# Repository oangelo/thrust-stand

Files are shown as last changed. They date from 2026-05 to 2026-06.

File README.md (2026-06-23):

# thrust-stand




## 📋 Sobre

Sistema embarcado baseado em ESP32 para monitoramento de testes estáticos de motores de foguetes, com aquisição de dados de empuxo e pressão em tempo real, armazenamento em cartão SD e comunicação via Serial/Bluetooth.

## 🚀 Quick Start

1. Clone o repositório

```bash
git clone https://github.com/ViniciusCMB/thrust-stand.git
```

2. Configure o hardware conforme [esquemático](./docs/HARDWARE.md)
3. Carregue o firmware

## 📁 Estrutura do Projeto

```
├── 📂 docs/              # Documentação técnica detalhada
├── 📂 extras/            # Códigos extras utilizados
├── 📂 firmware/          # Código do microcontrolador ESP32
├── 📂 hardware/          # Esquemáticos, PCBs e lista de componentes
├── 📂 software/          # Ferramentas de análise e interface
└── 📂 tests/             # Testes unitários e de integração
```

## 🔧 Pré-requisitos

- Hardware: ESP32 DevKit V1, célula de carga + HX711, sensor de pressão (com divisor resistivo), módulo microSD (SPI), 2 botões tácteis (`GPIO32` para TARE e `GPIO33` para novo arquivo), LED com resistor de limitação
- Software: Arduino IDE 2.0+
- Bibliotecas: ver `docs/FIRMWARE.md`

## 📖 Documentação

- [Esquemático e Montagem](./docs/HARDWARE.md)
- [Firmware e Arquitetura](./docs/FIRMWARE.md)
- [Protocolos e API](./docs/API.md)
- [Troubleshooting](./docs/TROUBLESHOOTING.md)

## 🎯 Funcionalidades

- ✅ Aquisição de dados de empuxo e pressão em tempo real
- ✅ Armazenamento em cartão SD com arquivos sequenciais
- ✅ Controle local por botões (TARE e novo arquivo)
- ✅ LED de status de gravação no SD
- ✅ Comunicação (Serial, Bluetooth)
- ✅ Calibração persistente da célula de carga

## 📊 Dados de Teste

Os dados de testes estáticos de motores específicos são armazenados no repositório dedicado:
[motor](https://github.com/Serra-Rocketry/motor)

Este repositório (thrust-stand) contém apenas o sistema de aquisição. Os dados coletados durante os testes devem ser commitados no repositório `motor`.

## 🤝 Contribuindo

Este projeto segue as [Boas Práticas da Serra Rocketry](https://github.com/Serra-Rocketry/best-practices). Para contribuir:

1. Fork o projeto
2. Crie uma branch para sua feature (`git checkout -b feature/AmazingFeature`)
3. Commit suas mudanças (`git commit -m 'Add some AmazingFeature'`)
4. Push para a branch (`git push origin feature/AmazingFeature`)
5. Abra um Pull Request

## ✨ Autores

- Equipe Serra Rocketry - Desenvolvimento e documentação
- Contribuidores - [Lista de contribuidores]()

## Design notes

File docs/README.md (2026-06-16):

# 📚 Documentação Técnica - Sistema de Teste Estático

Esta documentação reúne o necessário para montagem, calibração, operação e troubleshooting do sistema baseado em ESP32.

## 🗂️ Estrutura da Documentação

### 1. Guia de Instalação

- Requisitos de hardware e software
- Configuração do ambiente
- Primeira execução

### 2. [Hardware](./HARDWARE.md)

- Lista de componentes (BOM)
- Mapeamento de pinos e conexões
- Função dos botões e do LED

### 3. [Firmware](./FIRMWARE.md)

- Arquitetura e fluxo de aquisição
- Calibração da célula de carga
- Sistema de arquivos e armazenamento

### 4. [API e Protocolos](./API.md)

- Comandos seriais
- Controles físicos
- Exemplos de interação

### 5. [Troubleshooting](./TROUBLESHOOTING.md)

- Problemas comuns e diagnóstico rápido
- Procedimentos de correção

### 6. [Evolução da Caixa](./EVOLUÇÃO_CAIXA.md)

- Histórico das 3 versões da estrutura física
- Comparativo de materiais e design

### 7. [V3 Detalhes](./V3_DETALHES.md)

- Especificações da bancada v3
- Célula de carga, guia linear, resolução

## 📊 Diagramas Técnicos

Arquitetura do sistema:

```
[Sensores] -> [ESP32] -> [Armazenamento] -> [Comunicação]
    |            |             |               |
 Célula/HX711  Process.      microSD        Serial/BT
 Pressão       Dados         Arquivo CSV    Monitoramento
```

Fluxo de dados:

```mermaid
graph TD;
    A[Sensores] --> B[Aquisição];
    B --> C[Processamento];
    C --> D[Armazenamento SD];
    C --> E[Transmissão];
    D --> F[Arquivo CSV];
    E --> G[Serial];
    E --> H[Bluetooth];
```

## 🛠️ Recursos Técnicos

### Especificações do Sistema

- Microcontrolador: ESP32
- Sensores: célula de carga (HX711) e sensor de pressão analógico
- Armazenamento: cartão SD (SPI), com fallback para LittleFS
- Comunicação: Serial USB e Bluetooth
- Controles físicos:
  - Botão `GPIO32`: TARE
  - Botão `GPIO33`: iniciar novo arquivo
  - LED `GPIO4`: aceso durante gravação no SD

### Formatos de Dados

- Logs: CSV (`Tempo,Empuxo,Pressao`)
- Configuração: `Preferences` (fator de calibração)
- Comunicação: comandos por texto

## 🤝 Contribuindo para a Documentação

1. Reporte inconsistências encontradas
2. Proponha melhorias de texto e organização
3. Abra PR com correções objetivas

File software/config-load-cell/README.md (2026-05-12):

# Explicação do Sistema

Este sistema é composto pelos seguintes componentes principais:

1. **`firmware/firmware.ino`**: roda no ESP32 e transmite leituras (RAW e em unidades) via Serial.
2. **`software/config-load-cell/fator_de_calibracao/fator_de_calibracao_main.py`**: ferramenta GUI para calcular/enviar o fator de calibração.
3. **`software/config-load-cell/fator_de_calibracao/fator_de_calibracao_cli.py`**: utilitários/CLI de calibração (opcional).

- **Firmware**: coleta dados da célula de carga (HX711) e envia via Serial/Bluetooth.
- **GUI**: lê as amostras RAW do ESP32, calcula o fator e envia via comando `SET LOAD FACTOR`.

## Passo a Passo para Configurar uma Célula do Zero

1. **Montagem do Hardware**:

   - Conecte a célula de carga ao amplificador HX711.
   - Conecte o amplificador HX711 ao ESP32.

2. **Configuração do ESP32**:

    - Carregue o código `firmware/firmware.ino` no ESP32 usando a IDE Arduino.
   - Verifique se o ESP32 está enviando dados da célula de carga via comunicação serial.

3. **Calibração da Célula de Carga**:

    - Coloque um peso conhecido na célula.
    - Execute a GUI: `python software/config-load-cell/fator_de_calibracao/fator_de_calibracao_main.py`
    - Selecione a porta serial, clique em "Conectar" e depois em "Calcular".
    - Confirme/ajuste o valor e clique em "Enviar" para persistir no ESP32.

4. **Verificação Final**:
    - Reinicie o ESP32 e valide a leitura em `kgf` via Serial (o firmware faz log contínuo).

Obs.: os arquivos `Config.ino`, `Verify.ino`, `DadosSerial.py`, `Calibrar.py` são legados e não fazem parte do fluxo atual.

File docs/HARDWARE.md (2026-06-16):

# 🔌 Hardware - Sistema de Teste Estático

## 📋 Visão Geral do Sistema

Sistema embarcado baseado em ESP32 para aquisição de empuxo e pressão em testes estáticos de motores de foguetes, com gravação local de dados no cartão SD e telemetria via Serial/Bluetooth.

Controles físicos do esquemático atual:

- `GPIO32`: botão para TARE (zerar a célula de carga)
- `GPIO33`: botão para iniciar um novo arquivo de log no SD
- `GPIO4`: LED de indicador de funcionamento (aceso durante gravação no SD)

## 🧩 Lista de Componentes (BOM)

| Componente | Quantidade | Especificações |
| --- | --- | --- |
| ESP32 DevKit V1 | 1 | 30/38 pinos, WiFi/BT |
| Célula de carga | 1 | Compatível com HX711 |
| Módulo HX711 | 1 | ADC 24 bits para célula de carga |
| Sensor de pressão | 1 | 0-10 MPa, saída analógica 0.5-4.5V |
| Módulo microSD | 1 | Interface SPI |
| LED | 1 | 5mm, vermelho |
| Botão tátil (TARE) | 1 | 6x6mm |
| Botão tátil (novo arquivo)| 1 | 6x6mm |
| Resistores do divisor | 2 | 2.2kΩ e 3.3kΩ |
| Resistor do LED | 1 | 220Ω (valor típico) |
| Fonte de alimentação | 1 | 5V 2A (mínimo recomendado) |

## 🔄 Mapeamento de Conexões

| ESP32 | Função no sistema |
| ----- | --- |
| `GPIO26` | HX711 `DT` |
| `GPIO27` | HX711 `SCK` |
| `GPIO35` | Entrada do sensor de pressão (via divisor resistivo) |
| `GPIO5`  | microSD `CS` |
| `GPIO23` | microSD `MOSI` |
| `GPIO19` | microSD `MISO` |
| `GPIO18` | microSD `SCK` |
| `GPIO4`  | LED de gravação |
| `GPIO32` | Botão TARE |
| `GPIO33` | Botão novo arquivo |
| `VIN` | Alimentação 5V dos módulos |
| `GND` | Terra comum |

Observações de ligação:

- Botões: um terminal no GPIO correspondente e o outro no `GND`.
- LED: ligado ao `GPIO4` com resistor em série.
- Sensor de pressão: saída analógica passa por divisor resistivo antes de chegar ao `GPIO35`.

## 🛠️ Procedimento de Montagem

1. Preparação dos componentes

- Verifique todos os itens da BOM
- Teste ESP32 e cartão SD separadamente antes da montagem final

2. Sequência recomendada

- Conecte alimentação (`VIN` e `GND`)
- Conecte HX711 e célula de carga
- Conecte módulo microSD (SPI)
- Conecte sensor de pressão com divisor resistivo
- Conecte LED de status
- Conecte os dois botões (`GPIO32` e `GPIO33`)

3. Divisor resistivo para o sensor de pressão

```
Vsensor (0.5-4.5V) --- R1 (2.2kΩ) --- GPIO35
                         |
                        R2 (3.3kΩ)
                         |
                        GND
```

Cálculo do divisor:

```
Vout = Vsensor * (R2 / (R1 + R2))

# Exemplo
Vout_max = 4.5V * (3300 / (2200 + 3300)) = 2.7V
```

## 📷 Foto de Referência

Montagem completa:

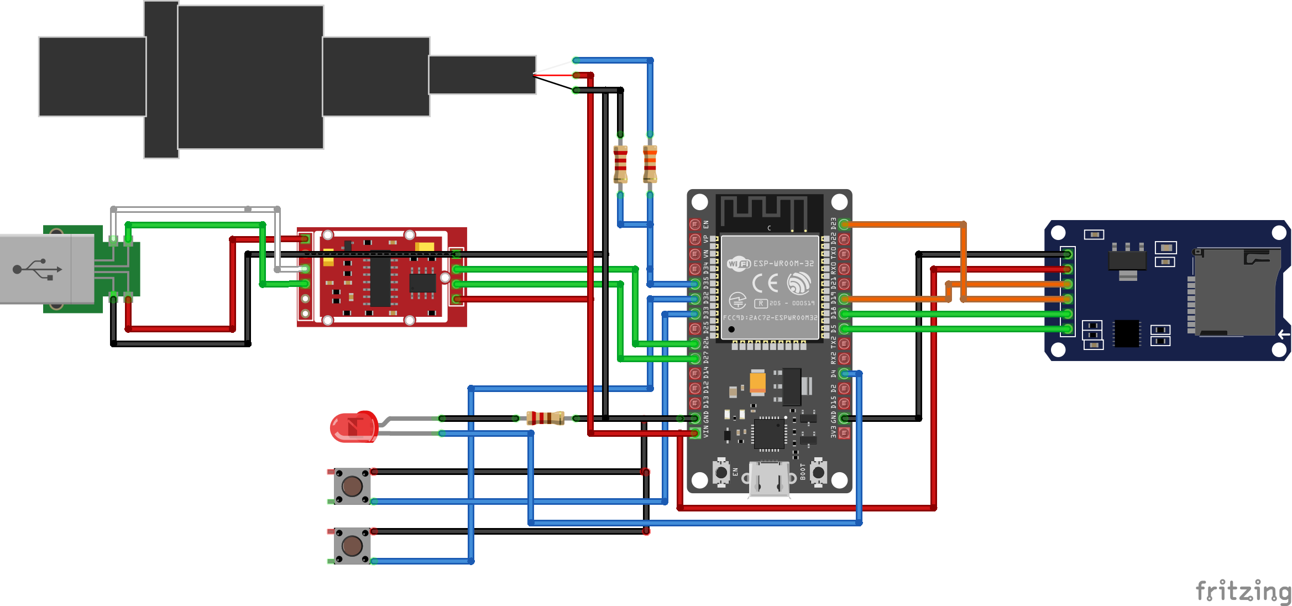
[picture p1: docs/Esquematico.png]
Esquemático


## ⚠️ Considerações de Projeto

- [x] Divisor resistivo no sensor de pressão
- [x] Terra comum entre todos os módulos
- [x] Botões dedicados para TARE e novo arquivo
- [x] LED dedicado para indicação de gravação no SD
- [ ] Isolamento contra vibrações
- [ ] Proteção contra poeira e umidade

## 🧪 Testes de Hardware

### Testes pré-montagem

- Continuidade dos cabos
- Tensão de alimentação estável
- Comunicação SPI com microSD
- Leitura de sensores individuais

### Testes pós-montagem

- Botão `GPIO32` realiza TARE
- Botão `GPIO33` inicia novo arquivo
- LED acende durante gravação no SD
- Leituras de empuxo e pressão estáveis

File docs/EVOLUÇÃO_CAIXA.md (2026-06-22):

# 📦 Evolução da Caixa de Teste Estático

## Visão Geral

Acompanha a evolução da estrutura física do sistema de teste estático ao longo de 3 versões, desde protótipo em alumínio até estrutura industrial em aço com guias lineares.

---

## V1 — Perfil V-slot 20×20mm (Alumínio)

### Estrutura

- Perfil de alumínio extrudado V-slot 20×20mm
- Formato: caixão retangular aberto
- Trilho central longitudinal
- Disco branco (prato de balança / plataforma de apoio)
- PCB verde conectada internamente
- Versão com rolamentos: dois rolamentos/flanges na travessa superior, placa de fixação metálica, eixo passante/suporte de motor

### Sensores

- 1 célula de carga fixada na base

### Fixação

- Parafusos na base (difícil de fixar no chão)

### Problemas

- Custo alto do perfil V-slot
- Robustez insuficiente
- Dificuldade de fixação no chão

### Fotos

<table>
  <tr>
    <td>V1 frontal superior</td>
    <td>V1 lateral superior</td>
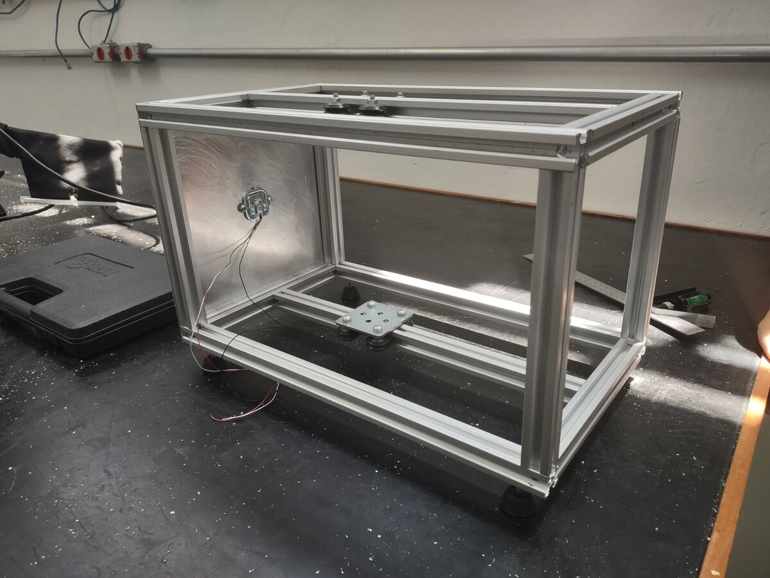
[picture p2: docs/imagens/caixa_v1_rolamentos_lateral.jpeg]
V1 com rolamentos
    <td></td>
  </tr>
</table>

### Vídeo

Teste estático V1 — alumínio

[Versão com áudio (MP4)](./videos/caixa_v1_teste_estatico.mp4)

---

## V2 — Metalon 20×20mm (Aço)

### Estrutura

- Tubo quadrado de aço (metalon) 20×20mm
- Geometria trapezoidal/triangulada (suporte para carga assimétrica)
- Pintada de preto
- Estrutura soldada (diferente da v1 modular com parafusos)

### Sensores

- 2 células de carga em encapsulamento preto
- Configuração Wheatstone (medição de empuxo + momento)

### Fixação

- Parafusos na base

### Problemas

- Soldagem difícil — estrutura ficou torta/desalinhada
- Abandonada devido à dificuldade de fabricação

### Fotos

<table>
  <tr>
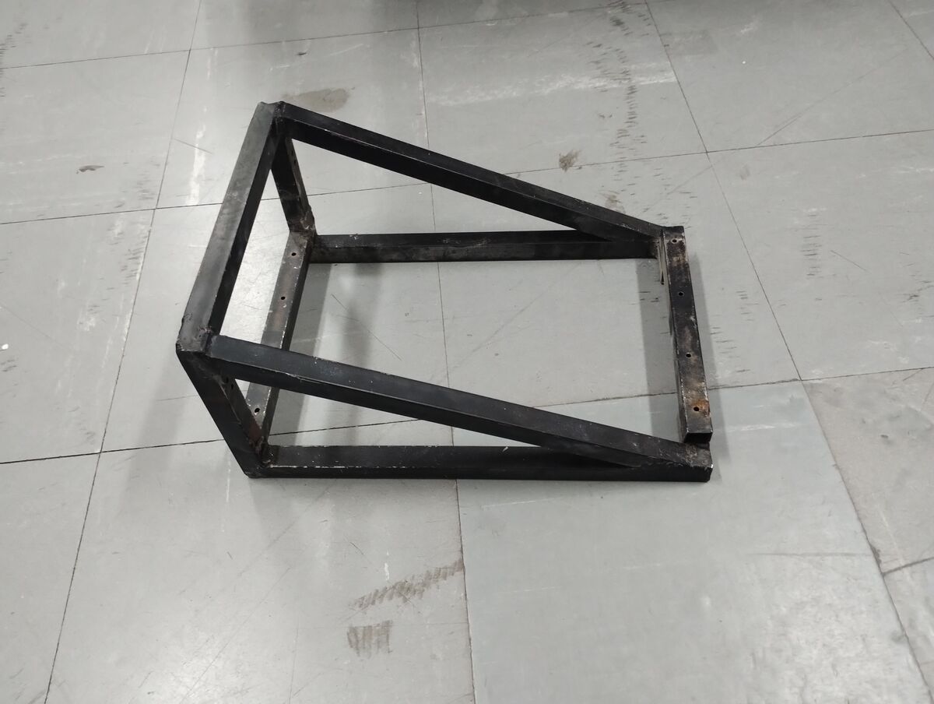
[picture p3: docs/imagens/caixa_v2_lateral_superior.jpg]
V2 lateral superior
    <td></td>
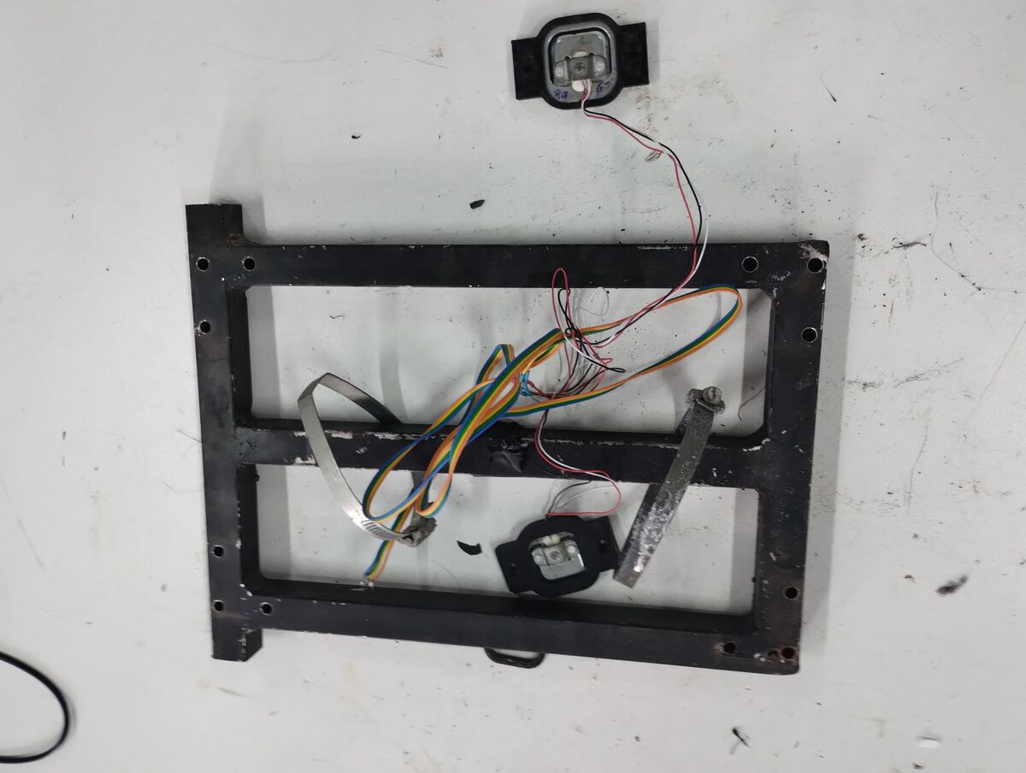
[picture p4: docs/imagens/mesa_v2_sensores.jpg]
V2 sensores
    <td></td>
  </tr>
</table>

### Vídeo

Teste estático V2 — metalon

[Versão com áudio (MP4)](./videos/caixa_v2_teste_estatico.mp4)

---

## V3 — Cantoneira 1″ × 1/4″ (Aço)

> Para especificações completas da V3, ver [V3_DETALHES.md](./V3_DETALHES.md).

### Estrutura

- Cantoneira de aço 1 polegada × 1/4 de polegada
- Mesa deslizante com trilhos lineares:
  - Dois eixos lineares cromados
  - Carrinhos lineares (rolamentos lineares)
  - Estrutura central deslizante
- Suporte de motor com fixação por flange
- Pintada de preto

### Sensores

- 1 célula de carga fixada na base

### Fixação

- Parafusos na base (melhorado em relação à v1)

### Render CAD

Mostra a base + estrutura deslizante completa. Design influenciado pelas iterações anteriores.

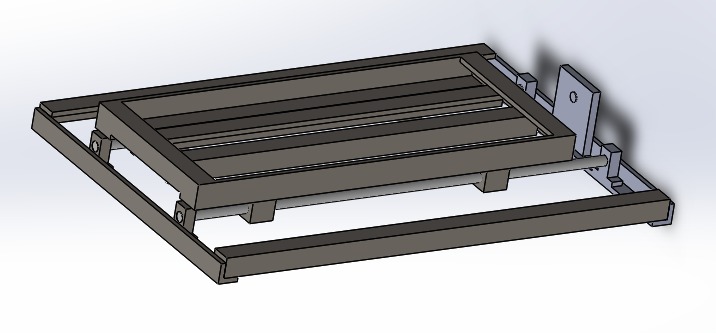
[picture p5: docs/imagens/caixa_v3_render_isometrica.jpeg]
V3 render isométrico


### Fotos

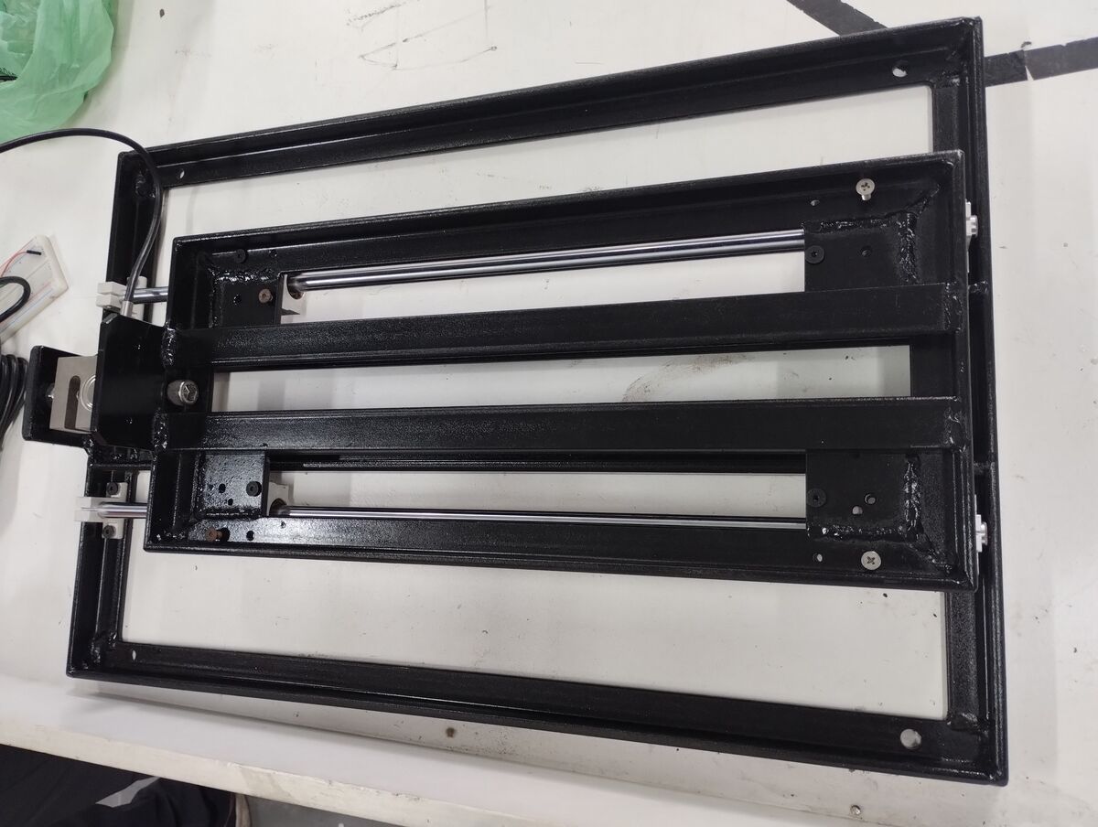
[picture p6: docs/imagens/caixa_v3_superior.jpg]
V3 superior


---

## Comparativo

| Aspecto | V1 | V2 | V3 |
| --- | --- | --- | --- |
| Material | Alumínio V-slot 20×20mm | Aço metalon 20×20mm | Aço cantoneira 1″ × 1/4″ |
| Geometria | Retangular | Trapezoidal | Retangular + mesa deslizante |
| Montagem | Modular (parafusos T-nut) | Soldada | Soldada + trilhos lineares |
| Células de carga | 1 | 2 (Wheatstone) | 1 |
| Fixação no chão  | Difícil | Melhor | Melhorada |
| Robustez | Baixa | Média | Alta |
| Custo relativo | Alto (perfil importado) | Baixo | Médio |
| Status | Abandonada | Abandonada (solda torta) | **Atual** |

---

## Conclusões

- **V1**: prototipagem rápida, explorou conceitos de guia linear e montagem modular, mas cara e frágil
- **V2**: tentativa de industrialização com geometria trapezoidal para cargas assimétricas, mas soldagem inadequada resultou em desalinhamento
- **V3**: evolução natural — combina robustez da cantoneira de aço com precisão de trilhos lineares e carrinhos, voltando à configuração de célula de carga única

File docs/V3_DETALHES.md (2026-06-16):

# 🔧 V3 — Detalhes Técnicos da Bancada

## Visão Geral

Especificações completas da versão 3 da bancada de teste estático da Serra Rocketry. Esta versão utiliza cantoneira de aço com sistema de guia linear para medição precisa de empuxo em motores experimentais de médio porte.

---

## Especificações Estruturais

| Componente | Especificação |
|---|---|
| Material da estrutura | Cantoneira de aço 1″ × 1/4″ |
| Pintura | Preto |
| Geometria | Retangular + mesa deslizante |

### Modelo CAD

[Baixar modelo STEP](../hardware/teste_estatico/step/caixa_v3.step)

---

## Sistema de Guia Linear

| Componente | Especificação |
|---|---|
| Mancal (suporte de eixo) | SK12 |
| Pillow Block (rolamento linear) | SC12UU |
| Eixo linear | ⌀12mm, comprimento 600mm |
| Tipo | Auto-alinhante (self-aligning) |
| Material do mancal | Alumínio fundido |
| Quantidade de eixos | 2 (paralelos, sem torção) |
| Fixação do Pillow Block | 16× parafusos M5×12mm |

<table>
  <tr>
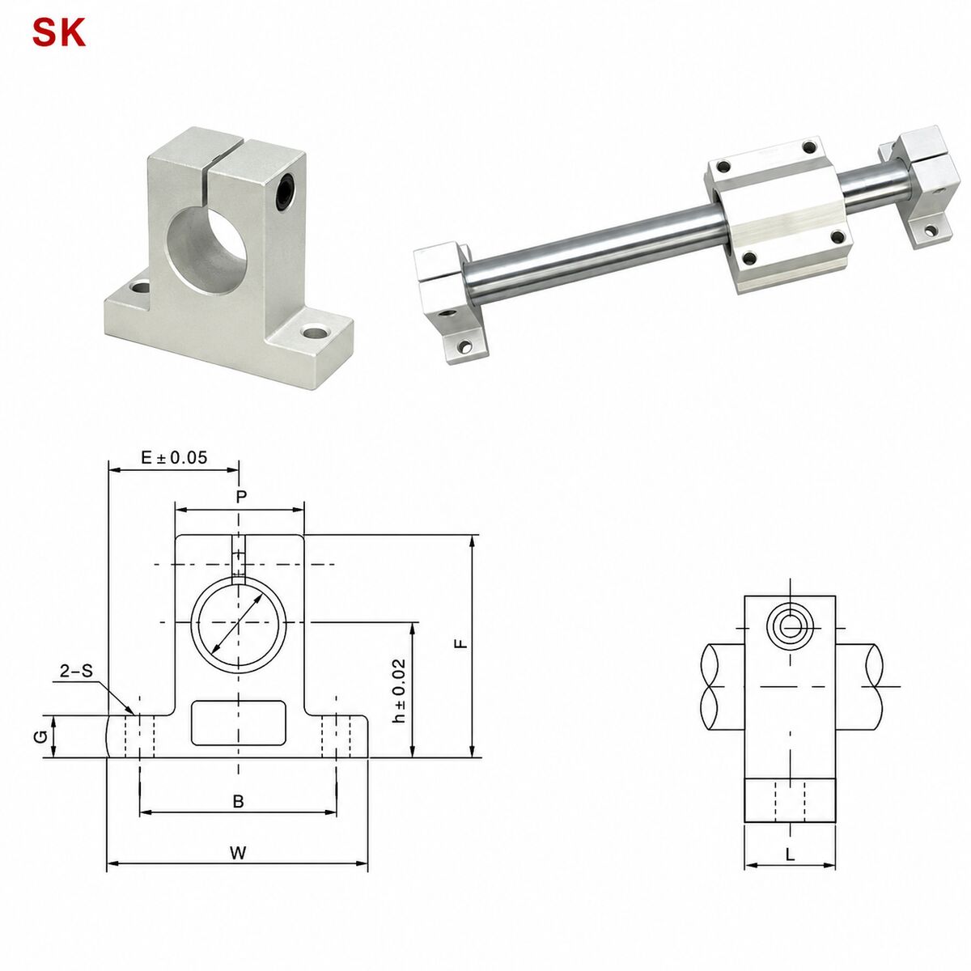
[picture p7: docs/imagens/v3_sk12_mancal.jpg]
Mancal SK12
    <td></td>
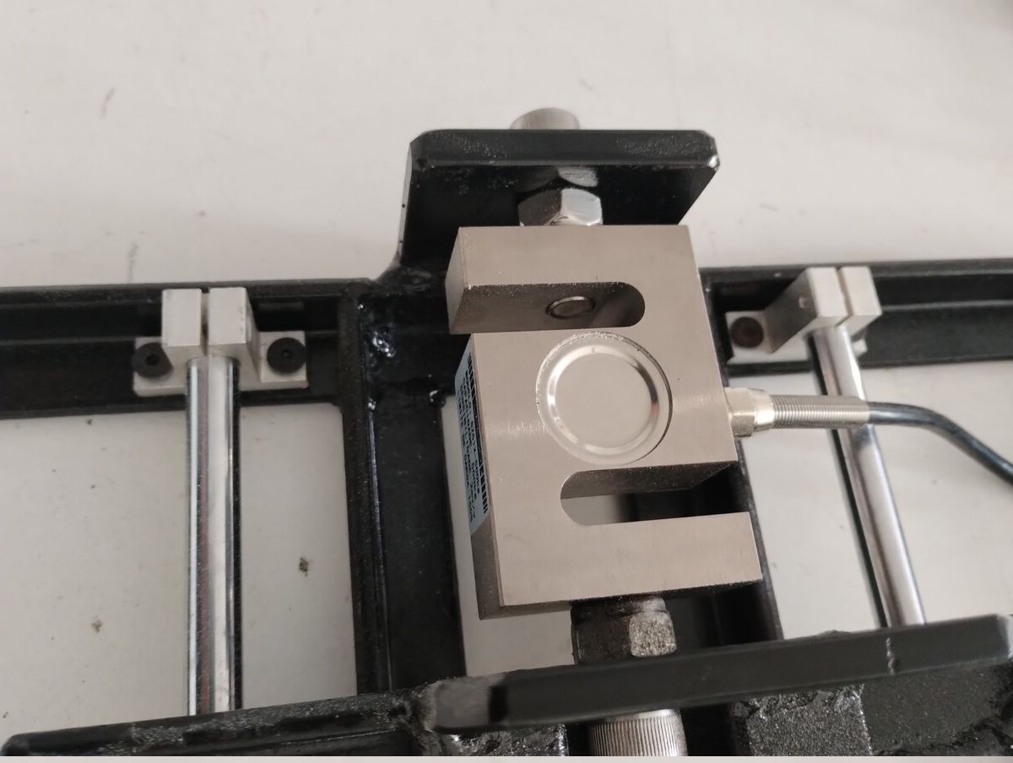
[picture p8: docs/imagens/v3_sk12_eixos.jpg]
Mancal SK12 com eixos lineares
    <td></td>
  </tr>
</table>

<table>
  <tr>
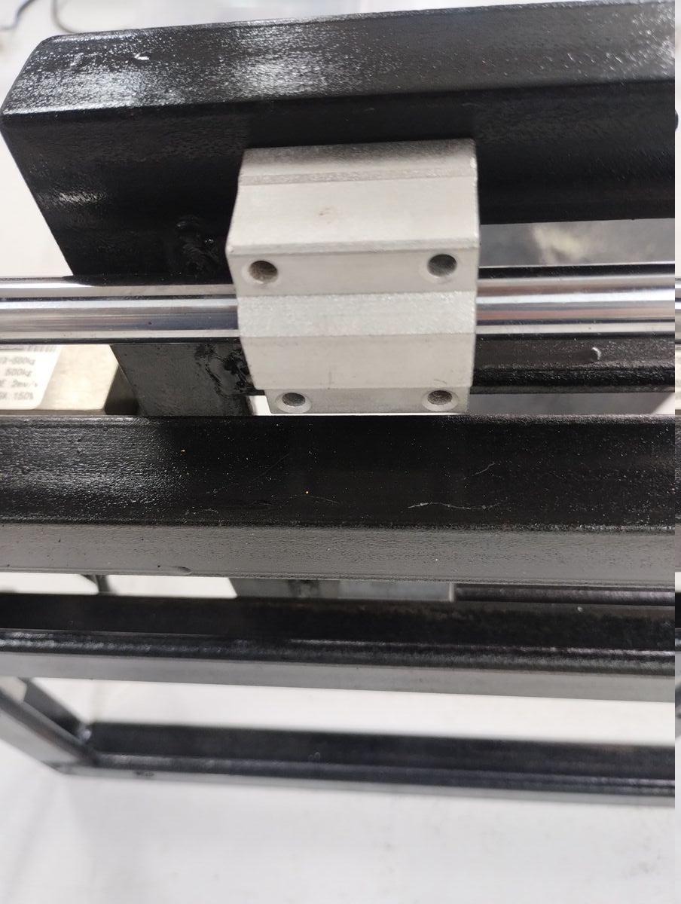
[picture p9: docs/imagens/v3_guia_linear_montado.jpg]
Guia linear montada
    <td></td>
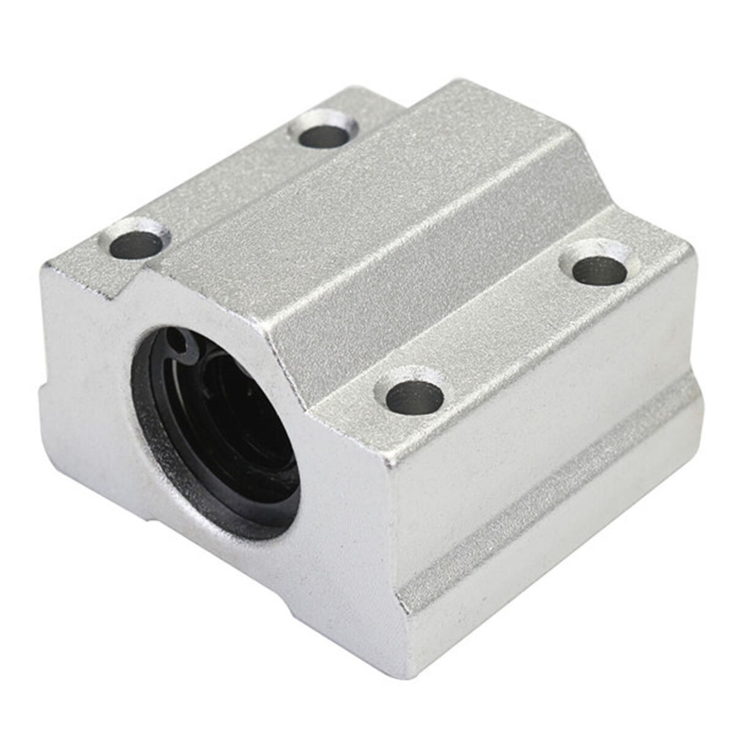
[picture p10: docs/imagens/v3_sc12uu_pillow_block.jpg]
Pillow Block SC12UU
    <td></td>
  </tr>
</table>

O sistema de guia linear permite que o carro da bancada mova-se axialmente, transmitindo o empuxo do motor para a célula de carga sem cargas laterais parasitas. Os dois eixos paralelos garantem ausência de torção.

---

## Célula de carga

### Modelo

**SZ51X-500kg** — Fabricante: PESO

- Tipo: Viga em S (shear beam)
- Material: Aço inox
- Configuração: Cisalhamento entre dois suportes metálicos

### Especificações (Certificado de Calibração)

| Parâmetro | Valor |
|---|---|
| Capacidade | 500 kgf (~4,9 kN) |
| Sensibilidade (full scale output) | 2,0 mV/V |
| Erro combinado | 0,02% F.S. |
| Não-linearidade | 0,02% F.S. |
| Repetibilidade | 0,01% F.S. |
| Histerese | 0,02% F.S. |
| Creep (30 min) | 0,02% F.S. |
| Sobrecarga segura | ±1,0% F.S. |
| Sobrecarga última | 150% F.S. |
| Impedância de entrada | 200 Ω |
| Impedância de saída | 350±5 Ω |
| Tensão de excitação | 5V (recomendado) / 12V (máx) |
| Temperatura compensada | -10 ~ +40°C |
| Temperatura de operação | -20 ~ +80°C |
| Aprovação QC | Pass 08 |

### Fiação

| Cor | Função |
|-----|---|
| Vermelho | E+ (Excitação +) |
| Preto | E− (Excitação −) |
| Verde | S+ (Sinal +) |
| Branco | S− (Sinal −) |

Célula de carga SZ51X-500kg

Célula de carga tipo viga em S em aço inox, montada em configuração de cisalhamento entre dois suportes metálicos da estrutura pintada de preto.

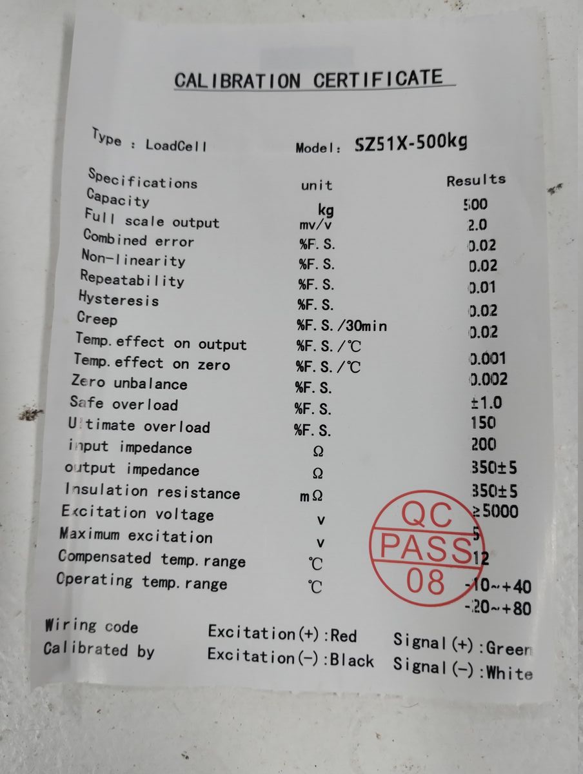
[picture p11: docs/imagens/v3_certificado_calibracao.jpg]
Certificado de calibração


Certificado do fabricante com especificações completas da SZ51X-500kg.

---

## Resolução Estimada

Com o HX711 (24 bits) ou ADS1232 na aquisição:

- **Fundo de escala:** 4,9 kN (500 kgf)
- **Resolução estimada:** ~0,5 N
- **Cobertura:** Motores experimentais de médio porte (Dédalo, Thonyan)

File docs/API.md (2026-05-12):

# 📡 API e Protocolos - Sistema de Teste Estático

## 📋 Visão Geral

Este documento descreve os protocolos de comunicação e as interfaces de controle do sistema de teste estático.

## 🔌 Protocolos Suportados

| Protocolo  | Tipo | Velocidade  | Alcance | Caso de Uso |
| --- | --- | --- | --- | --- |
| Serial USB | Fio | 115200 baud | Local | Configuração, calibração, debug |
| Bluetooth  | Wireless | 115200 baud | ~10 m | Telemetria/monitoramento |

## 💻 Comunicação Serial/Bluetooth

### Configuração padrão

```
BAUD_RATE = 115200
DATA_BITS = 8
PARITY = NONE
STOP_BITS = 1
FLOW_CONTROL = NONE
```

### Estrutura de comandos

```
COMANDO [PARAMETRO]
```

## 🎮 Comandos Disponíveis

### 1. Modo de configuração (calibração)

```
COMANDO: INIT CONFIG
RESPOSTA: Aguardando fator de carga...
USO: entra no modo de calibração da célula de carga

COMANDO: SET LOAD FACTOR <valor>
EXEMPLO: SET LOAD FACTOR 277306.0
RESPOSTA: Fator de carga atualizado
USO: salva o fator de calibração na memória persistente
```

### 2. Controle da célula de carga

```
COMANDO: TARE
RESPOSTA: Célula Zerada!
USO: zera a leitura atual da célula de carga
```

## 🕹️ Controles Físicos

| Entrada física | Pino ESP32 | Função |
| --- | --- | --- |
| Botão 1 | `GPIO32` | TARE da célula de carga |
| Botão 2 | `GPIO33` | Iniciar novo arquivo de log no SD |
| LED | `GPIO4` | Indicador de funcionamento (aceso ao gravar no SD) |

## 🎯 Exemplo de Interação

### Calibração da célula de carga

```
# Terminal -> ESP32
INIT CONFIG

# ESP32 -> Terminal
Aguardando fator de carga...
# (ESP32 envia leituras RAW continuamente)
152345
152348
152350

# Terminal -> ESP32
SET LOAD FACTOR 277306.0

# ESP32 -> Terminal
Fator de carga atualizado: 277306.00
Modo configuração finalizado
```

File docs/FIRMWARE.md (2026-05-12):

# ⚙️ Firmware - Sistema de Teste Estático

## 🏗️ Arquitetura do Sistema

### Visão Geral

O firmware implementa aquisição contínua de dados para testes estáticos, com leitura da célula de carga e do sensor de pressão, gravação em cartão SD e transmissão de logs via Serial/Bluetooth.

### Diagrama de Arquitetura

```
┌─────────────────┐    ┌──────────────────┐    ┌──────────────────┐
│   SENSORES      │    │    PROCESSAMENTO │    │     SAÍDAS       │
│                 │    │                  │    │                  │
│  Célula Carga   │───▶│   Aquisição      │───▶│  Cartão SD       │
│  Sensor Pressão │    │   Filtragem      │    │  Serial USB      │
│                 │    │   Formatação CSV │    │  Bluetooth       │
└─────────────────┘    └──────────────────┘    └──────────────────┘
         │                        │                        │
         └────────────────────────┼────────────────────────┘
                                  │
                         ┌──────────────────┐
                         │   CONTROLE       │
                         │                  │
                         │  Botão TARE      │
                         │  Novo arquivo    │
                         │  Estado do LED   │
                         └──────────────────┘
```

## 📁 Estrutura de Código

### Módulos Principais

```
firmware/
├── 📄 firmware.ino              # Arquivo principal
└── 📄 Pressure.h                # Classe sensor de pressão
```

### Dependências e Bibliotecas

- Wire
- HX711
- FS
- SD
- LittleFS
- SPI
- Pushbutton
- BluetoothSerial
- Preferences

Obs.: instale as bibliotecas acima no ambiente Arduino/PlatformIO.

## 🔧 Configuração e Calibração

### Preferências Persistentes

O sistema usa `Preferences` para salvar o fator de calibração da célula de carga.

```cpp
// Carregar configuração
loadFactor = preferences.getFloat("loadFactor", 277306.0);

// Salvar configuração
preferences.putFloat("loadFactor", loadFactor);
```

## 🔄 Fluxo de Execução

1. Inicialização (`setup()`)

```cpp
void setup() {
    Serial.begin(115200);
    SerialBT.begin("ESP32_BT");

    preferences.begin("app", false);
    loadFactor = preferences.getFloat("loadFactor", 277306.0);

    pressureSensor.begin();

    setupStorageAndFile();
    setupHX711();
}
```

2. Loop principal (`loop()`)

```cpp
void loop() {
    staticTest();  // coleta e log periódico

    // Botão 1: TARE da célula de carga
    // Botão 2: iniciar novo arquivo de log

    if (Serial.available()) {
        // comandos de calibração e controle
    }
}
```

## 📊 Aquisição de Dados

### Estrutura registrada

```csv
Tempo,Empuxo,Pressao
0,0.000000,0.000000
100,1.234567,1.902000
200,2.345678,1.955000
```

### Processo de log

- Leitura da célula de carga (`HX711`)
- Leitura do sensor de pressão (`PressureSensor`)
- Atualização de picos de leitura
- Escrita no arquivo CSV atual no SD/LittleFS
- Espelhamento da leitura em Serial/Bluetooth

## 🎮 Controle do Sistema

### Interface Serial/Bluetooth

Os comandos são recebidos pela Serial USB. A Bluetooth serial espelha mensagens de log/estado.

### Comandos disponíveis

| Comando | Descrição | Exemplo | Resposta esperada |
| --- | --- | --- | --- |
| INIT CONFIG | Entra em modo calibração | `INIT CONFIG` | Aguarda fator de carga |
| SET LOAD FACTOR | Define fator de carga | `SET LOAD FACTOR 277306.0` | Fator atualizado |
| TARE | Zera célula de carga | `TARE` | Célula zerada |

### Entradas físicas

- Botão em `GPIO32`: executa TARE da célula de carga
- Botão em `GPIO33`: inicia um novo arquivo para continuação do teste
- LED em `GPIO4`: aceso durante gravação no cartão SD

## 💾 Sistema de Arquivos

### Estratégia de armazenamento

- O firmware tenta inicializar o cartão SD
- Em falha do SD, usa LittleFS como fallback
- Arquivos são gerados em sequência (`Dados_001.txt`, `Dados_002.txt`, ...)

### Formato do arquivo de dados

```csv
Tempo,Empuxo,Pressao
0,0.000000,0.000000
100,1.234567,1.902000
```

## 📡 Comunicação

- Serial USB: configuração, calibração e debug
- Bluetooth: espelhamento de leituras/estado

## 🚀 Compilação e Upload

### Arduino IDE

1. Selecione a placa `ESP32 Dev Module`
2. Configure a porta serial correta
3. Verifique as bibliotecas instaladas
4. Compile e faça upload

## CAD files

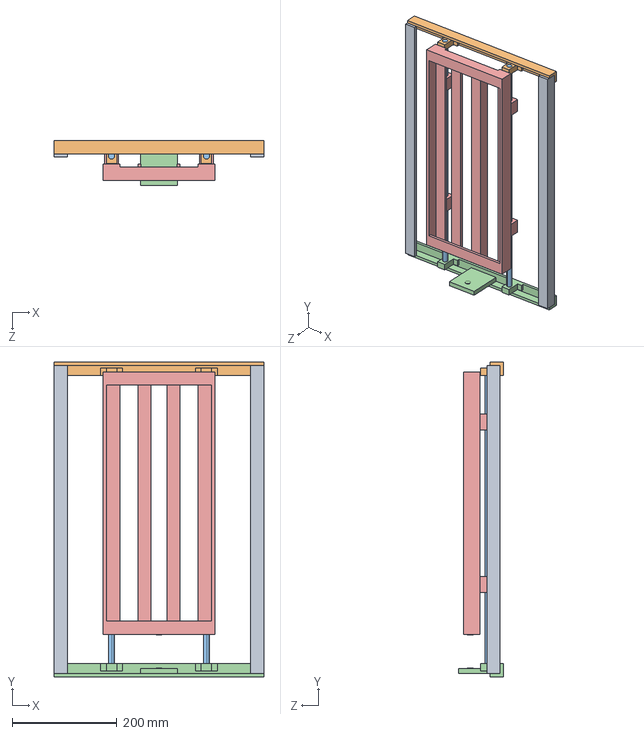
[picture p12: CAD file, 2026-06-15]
hardware/teste_estatico/step/caixa_v3.step
400.0 x 600.0 x 85.5 mm
Caixa_Teste_Estático_Basev3
Caixa_Teste_Estático_carrinhov3

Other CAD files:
hardware/teste_estatico/Fusion 360/testeserra1.f3z

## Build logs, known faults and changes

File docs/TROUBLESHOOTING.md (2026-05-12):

# 🐛 Troubleshooting - Sistema de Teste Estático

## 📋 Visão Geral

Guia rápido para diagnosticar falhas de alimentação, gravação no SD, leitura de sensores e controle por botões.

## 🔍 Diagnóstico Rápido

### LED de funcionamento (`GPIO4`)

| Estado do LED | Significado | Ação |
| --- | --- | ---- |
| Aceso | Sistema gravando no SD | Operação normal |
| Apagado durante gravação esperada | Sem escrita no arquivo atual | Verificar SD e fluxo de gravação |

### Botões físicos

| Botão | Pino | Função esperada |
| ----- | ---- | --- |
| Botão 1 | `GPIO32` | TARE da célula de carga |
| Botão 2 | `GPIO33` | Iniciar novo arquivo no SD |

## 🚨 Problemas Comuns e Soluções

### 1. 🔌 Problemas de alimentação

Sintomas:

- Sistema não liga
- Reinicializações aleatórias
- Leituras instáveis

Soluções:

```
1. Medir 5V em VIN e 3.3V no ESP32
2. Confirmar fonte com corrente suficiente (>= 2A recomendado)
3. Testar com outro cabo USB/fonte
4. Confirmar GND comum entre todos os módulos
```

### 2. 💾 Problemas com cartão SD

Sintomas:

- Falha ao iniciar armazenamento
- Arquivo não é criado
- LED não acende quando deveria gravar

Soluções:

```
1. Verificar formatação FAT32
2. Verificar conexões SPI: CS(5), MOSI(23), MISO(19), SCK(18)
3. Testar outro cartão SD
4. Verificar alimentação e GND do módulo SD
```

### 3. ⚖️ Problemas com célula de carga / HX711

Sintomas:

- Leitura travada em valor fixo
- Leitura muito ruidosa
- TARE não zera

Soluções:

```
1. Verificar DT(GPIO26) e SCK(GPIO27)
2. Verificar ligação da célula no HX711
3. Executar TARE pelo botão GPIO32 e por comando serial (TARE)
4. Repetir calibração com peso conhecido
```

### 4. 📊 Problemas com sensor de pressão

Sintomas:

- Leitura em 0 constante
- Saturação em valor máximo
- Oscilação elevada

Soluções:

```
1. Verificar alimentação do sensor
2. Verificar divisor resistivo (2.2kΩ e 3.3kΩ)
3. Medir tensão no GPIO35 (faixa esperada: 0-3.3V)
4. Conferir GND comum entre sensor e ESP32
```

### 5. 🎛️ Problemas nos botões

Sintomas:

- Botão de TARE não responde
- Botão de novo arquivo não cria novo log

Soluções:

```
1. Conferir ligação dos botões para GND
2. Conferir pinos corretos: GPIO32 (TARE), GPIO33 (novo arquivo)
3. Verificar mau contato no botão/chicote
4. Testar acionamento com monitor serial aberto
```

### 6. 📡 Problemas de comunicação Serial/Bluetooth

Sintomas:

- Sem dados no terminal serial
- Bluetooth não encontra o dispositivo

Soluções:

```
1. Confirmar baud rate 115200
2. Testar outro cabo USB
3. Confirmar porta serial correta
4. Reiniciar ESP32 e reconectar Bluetooth
```

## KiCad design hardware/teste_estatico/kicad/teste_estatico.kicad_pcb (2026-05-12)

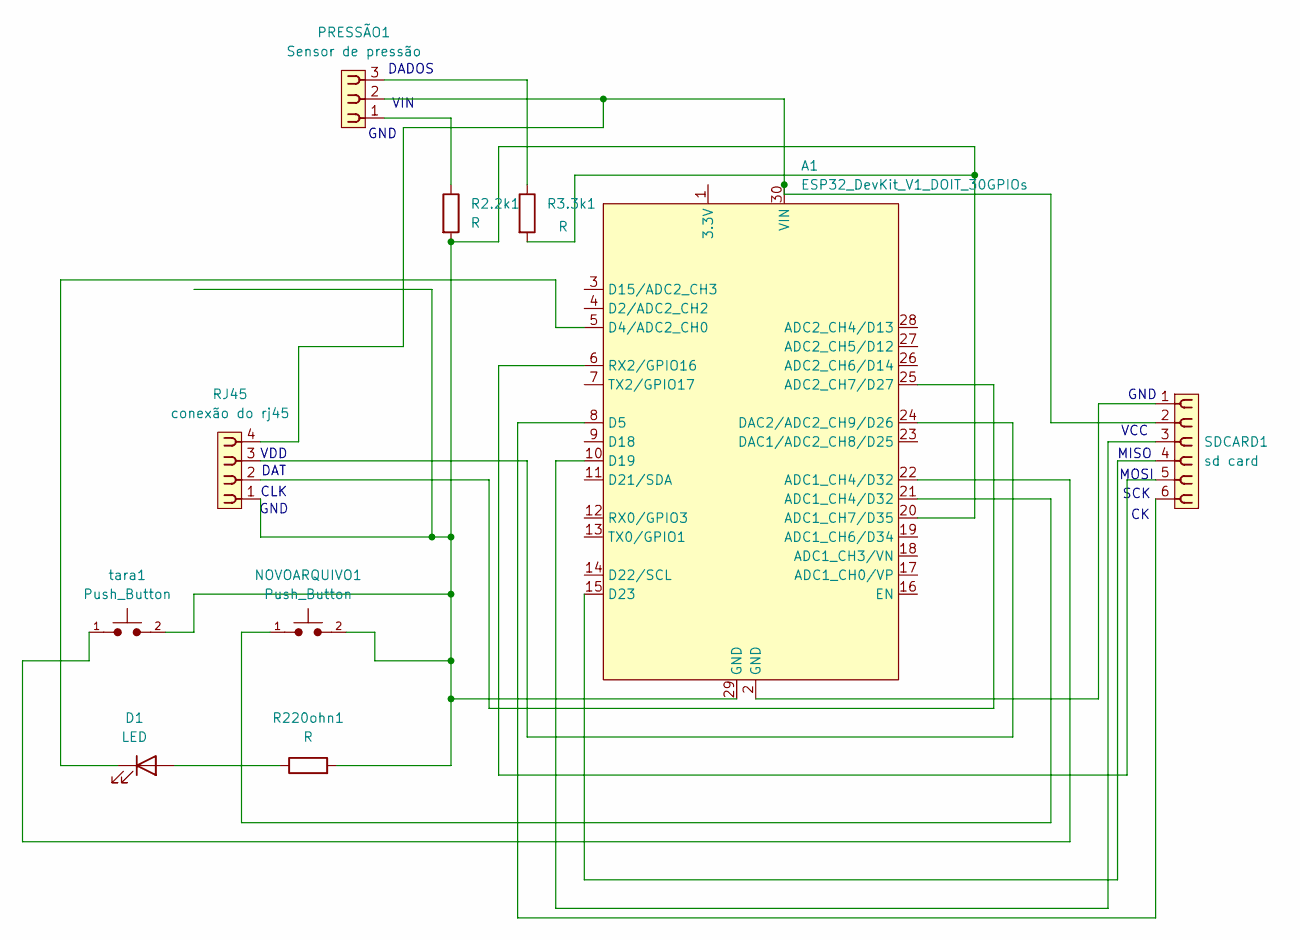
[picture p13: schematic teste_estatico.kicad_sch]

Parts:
A1: ESP32_DevKit_V1_DOIT_30GPIOs; DOIT_ESP32_DEVKIT_30Pins
D1: LED; LED_D5.0mm_FlatTop
NOVOARQUIVO1: Push_Button; SW_PUSH_6mm
PRESSÃO1: Sensor de pressão; PinSocket_1x03_P2.54mm_Vertical
R2.2k1, R3.3k1, R220ohn1: R; R_Axial_DIN0309_L9.0mm_D3.2mm_P12.70mm_Horizontal
RJ45: conexão do rj45; PinSocket_1x04_P2.54mm_Vertical
SDCARD1: sd card; PinSocket_1x06_P2.54mm_Vertical
tara1: Push_Button; SW_PUSH_6mm

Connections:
unnamed: A1.21 (ADC1_CH4/D32), NOVOARQUIVO1.1
unnamed: A1.22 (ADC1_CH4/D32), tara1.1
unnamed: A1.20 (ADC1_CH7/D35), A1.29 (GND), NOVOARQUIVO1.2, R2.2k1.2, R3.3k1.2, R220ohn1.2, RJ45.1, tara1.2
unnamed: A1.25 (ADC2_CH7/D27), RJ45.2
unnamed: A1.5 (D4/ADC2_CH0), D1.1 (K)
unnamed: A1.8 (D5), SDCARD1.6
unnamed: A1.10 (D19), SDCARD1.3
unnamed: A1.15 (D23), SDCARD1.4
unnamed: A1.24 (DAC2/ADC2_CH9/D26), RJ45.3
unnamed: A1.2 (GND), SDCARD1.1
unnamed: A1.6 (RX2/GPIO16), SDCARD1.5
unnamed: A1.30 (VIN), PRESSÃO1.2, RJ45.4, SDCARD1.2
unnamed: D1.2 (A), R220ohn1.1
unnamed: PRESSÃO1.1, R2.2k1.1
unnamed: PRESSÃO1.3, R3.3k1.1

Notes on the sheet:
DADOS
DAT
SCK
GND
CLK
VIN
VCC
MOSI
VDD
MISO

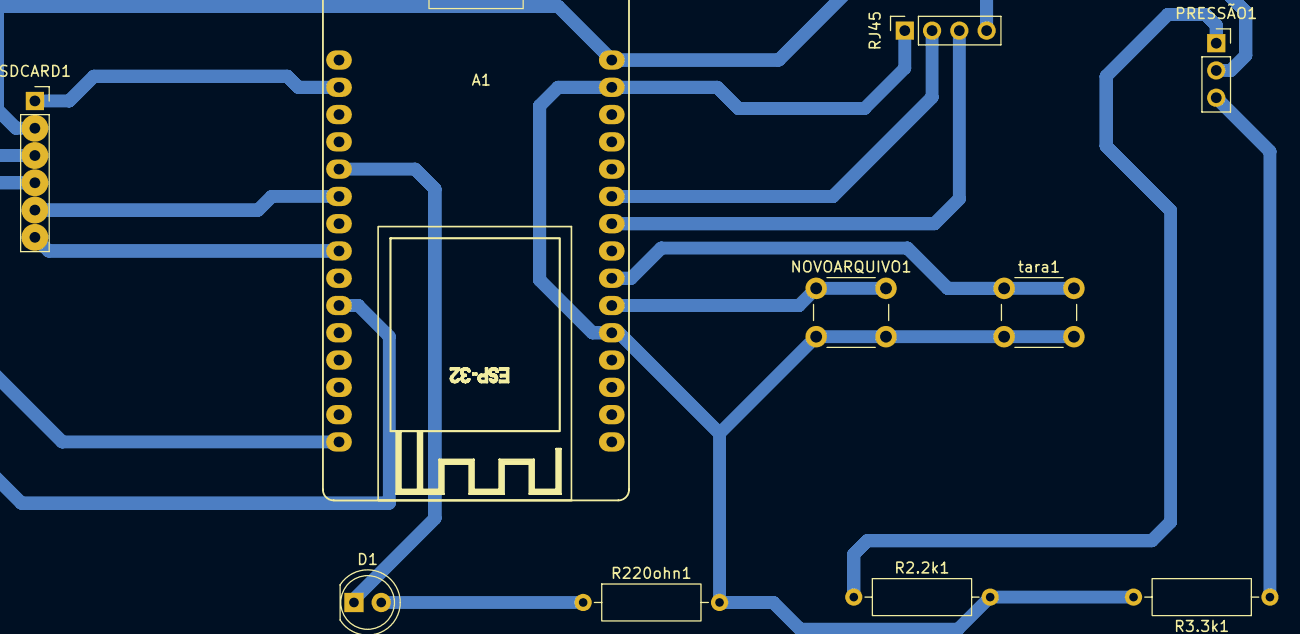
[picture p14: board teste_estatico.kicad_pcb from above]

Board: 2 copper layers, 10 parts (0 on the bottom side), 15 nets.

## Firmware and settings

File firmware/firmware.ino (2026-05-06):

// INCLUSÃO DE BIBLIOTECAS
#include <Wire.h>
#include <HX711.h>
#include <FS.h>
#include <SD.h>
#include <LittleFS.h>
#include <SPI.h>
#include <Pushbutton.h>
#include <BluetoothSerial.h>
#include <Preferences.h>

#include "Pressure.h"

// Definições de pinos e constantes
#define LED_PIN 4     // Pino do LED
#define CS_PIN 5      // Pino do cartão SD
#define BUZZER_PIN 33 // Pino do buzzer
#define BTN_PIN 32    // Pino do botão
#define CELULA_DT_PIN 26  // Pino de dados da célula de carga
#define CELULA_SCK_PIN 27 // Pino de clock da célula de carga
#define PRESSURE_PIN 35   // Pino do sensor de pressão
#define INTERVALO 100     // Precisão Leitura Dados milissegundos

// Sensores analógicos no ESP32 podem variar com atenuação/referência.
// Ajuste estes parâmetros ao seu hardware real para obter leituras coerentes.

// Variáveis globais
const float VinPressure = 5.0;    // Tensão que alimenta o sensor
const float VminPressure = 0.27;  // Tensão de saída em 0 MPa
const float VmaxPressure = 4.5;   // Tensão de saída em 10 MPa
const float maxPressure = 10.0;   // Pressão máxima do sensor em MPa
const float R1 = 2200.0;          // Resistor conectado entre o sensor e o pino do ESP32
const float R2 = 3300.0;          // Resistor conectado entre o pino do ESP32 e o GND
const int RESOLUCAO_ADC = 4095;   // ESP32 tem ADC de 12 bits (2^12 - 1)
const float TENSAO_MAX_ADC = 3.3; // Tensão de referência do ADC do ESP32
float maxValues[2] = {0.0, 0.0};  // Vetor leituras de pico (peso, pressão)
unsigned long previousMillis = 0; // Controle de tempo
bool selectLoop = false;          // Modo de operação
float loadFactor = 0.0;           // Valor encontrado na calibração
String filedir = "";              // Arquivo
String leitura = "";              // Leitura dos dados

enum StorageType { STORAGE_NONE, STORAGE_SD, STORAGE_LITTLEFS };
StorageType storageType = STORAGE_NONE;

// Estado do modo de configuração (calibração)
static bool configMode = false;

// Instanciação de objetos
Pushbutton button(BTN_PIN);                                                                                                  // Botão
PressureSensor pressureSensor(PRESSURE_PIN, R1, R2, RESOLUCAO_ADC, TENSAO_MAX_ADC, VminPressure, VmaxPressure, maxPressure); // Sensor de pressão

HX711 escala;                                                                                                                // Célula de carga
BluetoothSerial SerialBT;                                                                                                    // Bluetooth
Preferences preferences;                                                                                                     // Preferências salvas

void setup()
{
  // Inicialização da comunicação serial
  Serial.begin(115200);
  SerialBT.begin("ESP32_BT");

  preferences.begin("app", false);
  loadFactor = preferences.getFloat("loadFactor", 277306.0);

  pinMode(LED_PIN, OUTPUT);
  pinMode(BUZZER_PIN, OUTPUT);
  pinMode(BTN_PIN, INPUT);

  pressureSensor.begin();

  if (setupStorageAndFile() && setupHX711())
  {
    printToSerials("Sistema configurado. Transmitindo...");
    buzzSignal("Sucesso");
  }
  else
  {
    printToSerials("Falha crítica. Reiniciando...");
    buzzSignal("Alerta");
    delay(3000);
    ESP.restart();
  }
}

void loop()
{
  if (!configMode)
  {
    staticTest();
  }

  if (button.getSingleDebouncedPress())
  {
    buzzSignal("Beep");
    printToSerials("Célula Zerada!");
    escala.tare();
  }

  if (Serial.available())
  {
    String command = Serial.readStringUntil('\n');
    command.trim(); // Remove espaços e quebras de linha

    if (command.equalsIgnoreCase("TARE"))
    {
      buzzSignal("Beep");
      printToSerials("Célula Zerada!");
      escala.tare();
      return;
    }

    if (command.startsWith("INIT CONFIG"))
    {
      escala.tare();
      configMode = true;
      Serial.println("Aguardando fator de carga...");
      return;
    }

    if (configMode && command.startsWith("SET LOAD FACTOR"))
    {
      int lastSpaceIndex = command.lastIndexOf(' ');
      if (lastSpaceIndex != -1)
      {
        String factorStr = command.substring(lastSpaceIndex + 1);
        float factor = factorStr.toFloat();
        if (!isnan(factor) && factor != 0.0)
        {
          setLoadFactor(factor);
          configMode = false;
          Serial.println("Modo configuração finalizado");
        }
        else
        {
          printToSerials("Valor inválido. Tente novamente.");
          buzzSignal("Alerta");
        }
      }
      return;
    }
  }

  // Stream de calibração: RAW contínuo enquanto aguarda o fator
  if (configMode)
  {
    Serial.println(escala.get_value(1));
    delay(100);
  }
}

// Configuração do fator de carga
void setLoadFactor(float factor)
{
  loadFactor = factor;
  escala.set_scale(loadFactor);
  preferences.putFloat("loadFactor", loadFactor);
  printToSerials("Fator de carga atualizado: " + String(loadFactor, 2));
  buzzSignal("Sucesso");
}

// Sinalização com o buzzer
void buzzSignal(String signal)
{
  int frequency = 1000;   // Frequência do tom
  if (signal == "Alerta") // Alerta de erro em alguma configuração
  {
    for (int i = 0; i < 5; i++)
    {
      tone(BUZZER_PIN, frequency, 200);
      delay(200 + 150);
    }
  }
  else if (signal == "Sucesso") // Sinal de sucesso na configuração
  {
    for (int i = 0; i < 3; i++)
    {
      tone(BUZZER_PIN, frequency, 100);
      delay(100 + 100);
    }
  }
  else if (signal == "Ativado")
  {
    tone(BUZZER_PIN, frequency, 500);
  }
  else if (signal == "Beep") // Beep de funcionamento padrão
  {
    tone(BUZZER_PIN, frequency, 50);
  }
  else
  {
    Serial.println("Sinal inválido!");
  }
}


String generateFileName()
{
  const char* prefix = (storageType == STORAGE_SD) ? "Dados" : "dados";

  for (int i = 1; i <= 999; i++)
  {
    char candidate[32];
    snprintf(candidate, sizeof(candidate), "/%s_%03d.txt", prefix, i);

    bool exists = false;
    if (storageType == STORAGE_SD) {
      exists = SD.exists(candidate);
    } else if (storageType == STORAGE_LITTLEFS) {
      exists = LittleFS.exists(candidate);
    }

    if (!exists)
      return String(candidate);
  }

  return "/overflow.txt";
}

// Configuração do Storage (SD com LittleFS fallback)
bool setupStorage()
{
  Serial.println("Inicializando SD...");
  if (SD.begin(CS_PIN) && SD.cardType() != CARD_NONE)
  {
    storageType = STORAGE_SD;
    Serial.println("SD iniciado!");
    Serial.printf("Tipo: %s\n",
      SD.cardType() == CARD_MMC ? "MMC" :
      SD.cardType() == CARD_SD ? "SDSC" :
      SD.cardType() == CARD_SDHC ? "SDHC" : "UNKNOWN");
    return true;
  }

  Serial.println("SD falhou. Tentando LittleFS...");
  yield();

  if (LittleFS.begin(true))
  {
    storageType = STORAGE_LITTLEFS;
    Serial.println("LittleFS iniciado!");
    Serial.printf("Total: %u bytes, Usado: %u bytes\n",
      (unsigned)LittleFS.totalBytes(), (unsigned)LittleFS.usedBytes());
    return true;
  }

  Serial.println("ERRO: Nenhum storage disponivel!");
  yield();
  return false;
}

// Configuração do Storage e Arquivo
bool setupStorageAndFile()
{
  if (!setupStorage())
  {
    return false;
  }

  filedir = generateFileName();
  Serial.print("Arquivo: ");
  Serial.println(filedir);

  if (!writeFile(filedir, "Tempo,Empuxo,Pressao\n"))
  {
    printToSerials("Falha ao criar arquivo");
    return false;
  }

  printToSerials("Arquivo criado: " + filedir);
  return true;
}

// Configuração da célula de carga HX711
bool setupHX711()
{
  Serial.println("Iniciando HX711...");
  escala.begin(CELULA_DT_PIN, CELULA_SCK_PIN);
  Serial.println("HX711.begin OK");

  escala.set_scale(loadFactor);
  Serial.println("set_scale OK");

  escala.tare();
  Serial.println("tare OK");

  printToSerials("HX711 conectado");
  return true;
}

// Função para registrar e imprimir os dados do momento
// Formato: Tempo (ms), Empuxo (Kg), Pressão (MPa)
void logData(unsigned long millis)
{
  float peso = escala.get_units();
  float pressao = pressureSensor.readMPa();

  if (peso > maxValues[0])
  {
    maxValues[0] = peso;
  }

  if (pressao > maxValues[1])
  {
    maxValues[1] = pressao;
  }

  leitura = String(millis) + "," + String(peso, 6) + "," + String(pressao);

  printToSerials(leitura);
  appendFile(filedir, leitura);
}

// Escrita de dados em um arquivo
bool writeFile(const String &path, const String &message)
{
  File file;

  if (storageType == STORAGE_SD) {
    file = SD.open(path, FILE_WRITE);
  } else if (storageType == STORAGE_LITTLEFS) {
    file = LittleFS.open(path, FILE_WRITE);
  } else {
    return false;
  }

  if (!file)
  {
    printToSerials("Falha ao abrir o arquivo");
    return false;
  }
  if (file.print(message))
  {
    digitalWrite(LED_PIN, HIGH);
  }
  else
  {
    printToSerials("Falha ao escrever no arquivo");
    digitalWrite(LED_PIN, LOW);
    file.close();
    return false;
  }
  file.close();
  return true;
}

// Anexação de dados em um arquivo
void appendFile(const String &path, const String &message)
{
  File file;

  if (storageType == STORAGE_SD) {
    file = SD.open(path, FILE_APPEND);
  } else if (storageType == STORAGE_LITTLEFS) {
    file = LittleFS.open(path, FILE_APPEND);
  } else {
    return;
  }

  if (!file)
  {
    printToSerials("Falha ao abrir o arquivo");
    return;
  }
  if (file.print(message + "\n"))
  {
    digitalWrite(LED_PIN, HIGH);
  }
  else
  {
    printToSerials("Falha ao escrever no arquivo");
    digitalWrite(LED_PIN, LOW);
  }
  file.close();
}

// Criação de diretório
void createDir(fs::FS &fs, const String &path)
{
  if (fs.mkdir(path))
  {
    printToSerials("Dir created");
  }
  else
  {
    printToSerials("mkdir failed");
  }
}

// Função para imprimir na Serial e SerialBT
void printToSerials(const String &message)
{
  Serial.println(message);
  SerialBT.println(message);
}

// Função de teste estático
void staticTest()
{
  unsigned long currentMillis = millis();
  if (currentMillis - previousMillis > INTERVALO)
  {
    logData(currentMillis);
    previousMillis = currentMillis;
  }
}

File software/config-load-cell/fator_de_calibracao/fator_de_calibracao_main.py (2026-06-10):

import sys
from PySide6.QtWidgets import QApplication, QMainWindow
from PySide6.QtCore import QThread, Signal
import fator_de_calibracao_cli as fact_cli
import ui_fator_de_calibracao as fact_ui
import logging


class SamplerThread(QThread):
    """Coleta amostras da serial em background, sem travar a UI."""

    progress        = Signal(int)   # 0–100
    sample_received = Signal(int)   # valor de cada amostra
    finished        = Signal(list)  # lista final de amostras
    error           = Signal(str)   # mensagem de erro

    def __init__(self, com: fact_cli.Receiver, n_samples: int = 100):
        super().__init__()
        self.com = com
        self.n_samples = n_samples
        self._running = True

    def run(self):
        samples = []
        sample_count = 0

        # Garante que o ESP está em configMode antes de coletar.
        # Manda INIT CONFIG e aguarda a confirmação, com até 10 tentativas.
        confirmed = False
        for attempt in range(10):
            self.com.serial.reset_input_buffer()
            self.com.send_command(b'INIT CONFIG\n')
            # Lê algumas linhas esperando a confirmação
            for _ in range(5):
                line = self.com.read_response()
                print(f"[handshake] {repr(line)}")
                if 'Aguardando' in line or 'CONFIG' in line.upper():
                    confirmed = True
                    break
            if confirmed:
                print(f"[handshake] configMode confirmado na tentativa {attempt + 1}")
                break

        if not confirmed:
            self.error.emit('ESP não confirmou modo de calibração. Verifique a conexão.')
            return

        # Limpa qualquer lixo que chegou durante o handshake
        self.com.serial.reset_input_buffer()

        try:
            while self._running and self.com.check_connection() and sample_count < self.n_samples:
                raw = self.com.read_response()
                print(f"raw={repr(raw)}")
                value = fact_cli.try_parse_int(raw)
                if value is None:
                    continue
                samples.append(value)
                sample_count += 1
                self.sample_received.emit(value)
                self.progress.emit(int(sample_count / self.n_samples * 100))
        except Exception as e:
            self.error.emit(str(e))
            return

        self.finished.emit(samples)

    def stop(self):
        self._running = False


class Calibrator:

    def __init__(self):
        self.app = QApplication(sys.argv)
        self.window = QMainWindow()
        self.ui = fact_ui.Ui_MainWindow()
        self.logger = logging.getLogger('Calibrator')
        self.ui.setupUi(self.window)
        self.stopper = extend_ui(self.ui)
        self.window.show()
        self.app.exec()
        self.stopper()  # para a thread antes de destruir tudo


def extend_ui(ui):

    dummy_elements = False
    state = {
        'com': None,
        'thread': None,
    }

    def update_port_list():
        ports = fact_cli.list_ports()
        ui.cbox_seriais.clear()
        ui.cbox_seriais.addItems(['dummy-data-4', 'dummy-data-5', 'dummy-data-6']) if dummy_elements else None
        ui.cbox_seriais.addItems(ports)

    def connect_esp():
        port = str(ui.cbox_seriais.currentText())
        print(f"{port=}")
        try:
            state['com'] = fact_cli.Receiver(port)
        except Exception as e:
            ui.display_status.setText(f'Erro: {e}')
            return
        state['com'].serial.reset_input_buffer()
        print(f"com={state['com']}")
        ui.display_status.setText('Conectado')

    def send_factor():
        com = state['com']
        print(f"{com=}")
        if com is None:
            ui.display_status.setText('Desconectado')
            return
        fator = ui.line_edit_fator.text().strip().replace(',', '.')
        comma = f'SET LOAD FACTOR {fator}\n'
        print(f"-> {comma.strip()}")
        com.serial.reset_input_buffer()
        com.serial.write(comma.encode('utf-8'))
        com.serial.flush()
        for _ in range(10):
            line = com.read_response()
            if line:
                print(line)

    def on_sample_received(value):
        print(f"sample: {value}")

    def on_progress(value):
        ui.progressBar.setValue(value)

    def on_finished(samples):
        print(f"Coleta finalizada: {len(samples)} amostras")
        ui.btn_calcular.setEnabled(True)
        ui.display_status.setText('Conectado')

        expected_weight_str = ui.lineEdit_4.text()
        if not expected_weight_str:
            ui.display_status.setText('Informe o Peso Real')
            return
        try:
            expected_weight = float(expected_weight_str.replace(',', '.'))
        except ValueError:
            ui.display_status.setText('Peso Real inválido')
            return

        if not samples:
            ui.display_status.setText('Nenhuma amostra recebida')
            return

        calibration_factor = fact_cli.get_calibration_factor(samples, expected_weight)
        ui.line_edit_fator.setText(str(calibration_factor))

    def on_error(msg):
        print(f"Erro na thread: {msg}")
        ui.display_status.setText(f'Erro: {msg}')
        ui.btn_calcular.setEnabled(True)

    def calculate_factor():
        com = state['com']
        print(f"{com=}")

        if com is None:
            ui.display_status.setText('Desconectado')
            return

        expected_weight_str = ui.lineEdit_4.text()
        if not expected_weight_str:
            ui.display_status.setText('Informe o Peso Real')
            return

        if state['thread'] is not None and state['thread'].isRunning():
            return

        ui.btn_calcular.setEnabled(False)
        ui.display_status.setText('Iniciando calibração...')
        ui.progressBar.setValue(0)

        thread = SamplerThread(com, n_samples=100)
        thread.progress.connect(on_progress)
        thread.sample_received.connect(on_sample_received)
        thread.finished.connect(on_finished)
        thread.error.connect(on_error)
        state['thread'] = thread
        thread.start()

    def stop_all():
        if state['thread'] is not None and state['thread'].isRunning():
            state['thread'].stop()
            state['thread'].wait()

    ports = fact_cli.list_ports()
    ui.cbox_seriais.addItems(['dummy-data-1', 'dummy-data-2', 'dummy-data-3']) if dummy_elements else None
    ui.cbox_seriais.addItems(ports)

    ui.btn_atualizar.clicked.connect(update_port_list)
    ui.btn_calcular.clicked.connect(calculate_factor)
    ui.btn_conectar.clicked.connect(connect_esp)
    ui.btn_enviar.clicked.connect(send_factor)

    return stop_all


if __name__ == '__main__':
    Calibrator()

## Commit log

2026-05-09 Atualiza projeto KiCad
    [freerouting.dsn, temp-freerouting.dsn, teste_estatico.kicad_pcb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]
2026-05-11 adcionado arquivos pcb fusion 360
    [testeserra1.f3z]
2026-05-11 adcionado atulização nos arquivos de pcb kicad
    [freerouting.dsn, teste_estatico.kicad_pcb]
2026-06-15 docs: adiciona AGENTS.md com guia de estilo e comandos de build
    Instruções para agentes de IA cobrindo: comandos de build/upload do firmware Arduino/ESP32, execução de ferramentas Python, convenções de código C++ e Python, organização do repositório e armadilhas 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
2026-06-15 docs: reorganiza fotos da caixa v1 e limpa backups do KiCad
    - Move fotos da caixa para docs/imagens/ com nomes normalizados
    - Remove backups automáticos do KiCad do versionamento
    - Adiciona *-backups/ e *.kicad_prl ao .gitignore
2026-06-15 docs: adiciona documentação da evolução da caixa de teste
    Documenta as 3 versões da estrutura física:
    - V1: perfil V-slot 20x20mm (alumínio) — protótipo, cara e frágil
    - V2: metalon 20x20mm (aço) — trapezoidal, abandonada (solda torta)
    - V3: tubo 1" x 1/4" (aço) — atual, com trilhos lineares
2026-06-15 docs: corrige material da v3 — cantoneira, não tubo
2026-06-15 docs: atualiza AGENTS.md com convenções de imagens e remotes
2026-06-15 hardware: adiciona STEP da caixa v3
    [caixa_v3.step]
2026-06-16 docs: adiciona documentação detalhada da bancada v3
    - Especificações da célula de carga SZ51X-500kg (PESO)
    - Sistema de guia linear (eixo ⌀12mm, rolamento SC12UU)
    - Resolução estimada: ~0,5N em 4,9kN
    - 4 fotos de componentes
2026-06-16 docs: comprime imagens para 1200px e remove EXIF
    Reduzido de 34MB para 1.2MB (96% de redução).
    - Redimensionado para 1200px largura
    - Qualidade JPEG 80
    - Metadados EXIF removidos
2026-06-16 docs: formata imagens com tabelas HTML e click-to-zoom
    - Imagens em tabelas HTML para layout lado a lado (3 por linha)
    - Imagens isoladas para renders e documentos importantes
    - Largura: 300px (tabelas) e 500px (isoladas)
    - Click-to-zoom nativo do GitHub
2026-06-16 docs: reorganiza V3_DETALHES.md e corrige nomenclatura SK12/SC12UU
    - Renomeia v3_mancal_sc12uu.jpg → v3_sk12_mancal.jpg (mancal/suporte de eixo)
    - Renomeia v3_rolamento_sc12uu.jpg → v3_sc12uu_pillow_block.jpg (rolamento linear)
    - Adiciona v3_sk12_eixos.jpg (mancal com eixos lineares)
    - Reorganiza documento por componente (guia linear → célula → resolução)
    - Remove seção 'Fotos' separada, specs e fotos juntas por componente
2026-06-16 docs: coloca fotos do SK12 lado a lado na seção de guia linear
2026-06-16 docs: adiciona specs de fixação do Pillow Block SC12UU
2026-06-16 docs: atualiza AGENTS.md com convenções de imagens e V3_DETALHES.md
2026-06-22 docs: adiciona vídeos de teste estático V1 e V2
    - Move vídeos da raiz para docs/videos/ com nomes descritivos
    - Configura Git LFS para arquivos .mp4
    - Adiciona seções de vídeo em EVOLUÇÃO_CAIXA.md (V1 e V2)
    - Atualiza AGENTS.md com convenção de vídeos
2026-06-22 docs: usa tag <video> para playback inline no GitHub
2026-06-22 docs: usa AVIF animado para playback inline de vídeos
    - Converte vídeos de teste estático para AVIF (500px, 15fps)
    - V1: 334 KB, V2: 319 KB (vs 2.4 MB e 9.7 MB originais)
    - Embed com sintaxe ![alt](./imagens/file.avif) no GitHub
    - Mantém links para MP4 originais com áudio
    - Atualiza AGENTS.md com convenção de conversão SVT-AV1
2026-06-22 docs: ajusta largura dos vídeos AVIF para 300px
2026-06-23 docs: adiciona convenção de armazenamento de dados de teste
    - Remove pastas de backup redundantes (hardware/teste_estatico/*-backups/)
    - Adiciona fp-info-cache ao .gitignore
    - README.md: seção 'Dados de Teste' apontando para Serra-Rocketry/motor
    - AGENTS.md: seção 'Data Storage Conventions' definindo onde armazenar dados
